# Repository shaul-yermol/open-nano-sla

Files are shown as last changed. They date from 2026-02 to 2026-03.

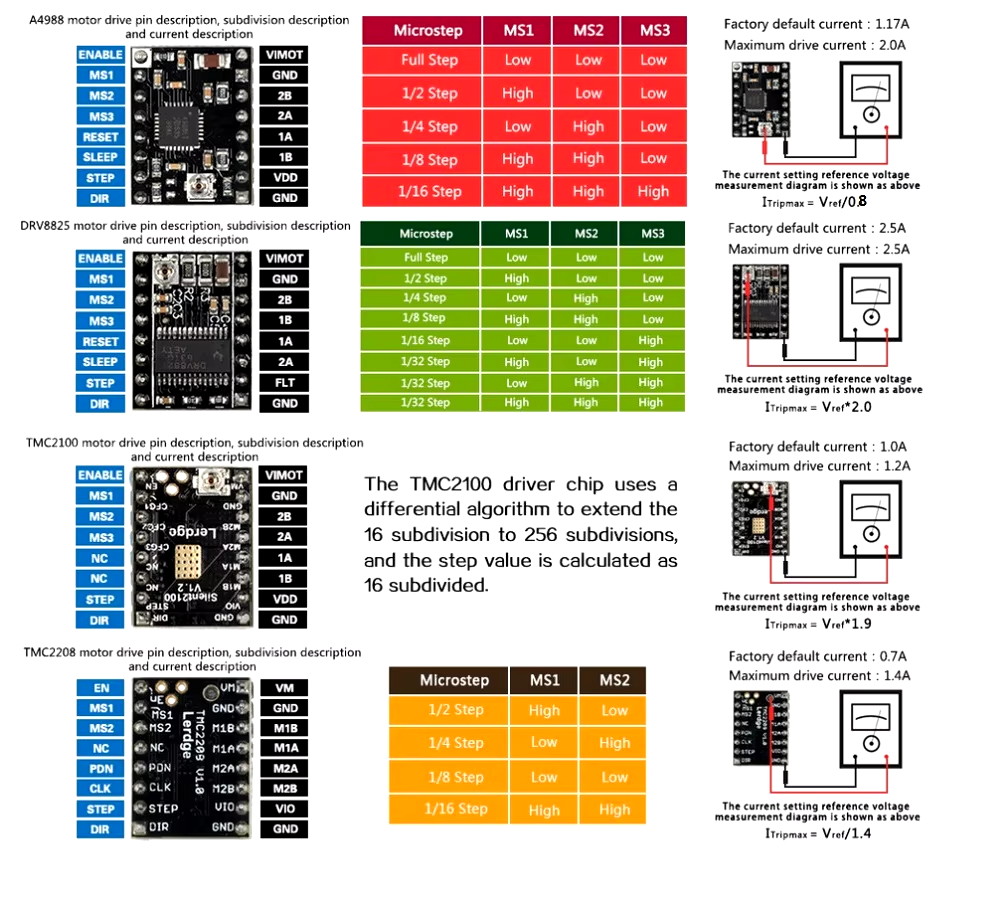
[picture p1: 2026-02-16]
cad/nano-dlp/microsteps.png

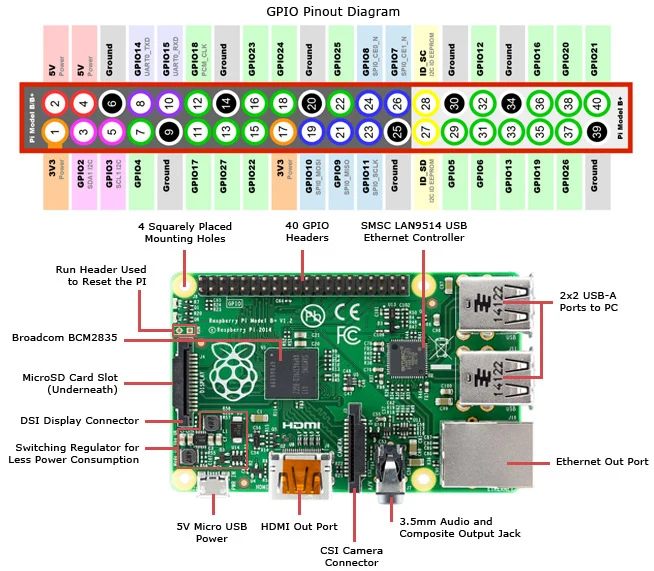
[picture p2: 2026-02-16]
cad/nano-dlp/Pi3_connectors.png

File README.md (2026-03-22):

# Set static IP for Raspberry Pi via cmdline.txt

Example of /boot/cmdline.txt:
ip=192.168.5.100::192.168.5.101:255.255.255.0:rpi:eth0:off

# Wnable WIFI via cmdline.txt

nmcli networking on
nmcli device wifi connect 3C:84:6A:58:4C:27 password "your-password"
sudo nmcli device wifi connect 00:B8:C2:B1:13:42 password
sudo route del 192.168.5.101

# Toggle UV light via GPIO
gpioset GPIO26=0

# Reading endstop state
## TOP:
gpiomon GPIO25
## BOTTOM:
gpiomon GPIO13

# Step motor driver:
DRV8825
1/32 microstepping
STEP = GPIO23
DIR = GPIO22
ENABLE=GPIO24 (active low)

```
# Enable driver
gpioset GPIO24=0
# Step forward 100 steps
for i in `seq 100`; do gpioset -t 1,1,0 GPIO23=1; done
# Step backward 100 steps
for i in `seq 100`; do gpioset -t 1,1 GPIO23=0; gpioset -t 1,1 GPIO23=1; done
# Disable driver
gpioset GPIO24=1
```

# Show images on HDMI display
sudo apt-get install fbi
sudo fbi -T 2 -d /dev/fb0 -noverbose [imagefile.jpg] 

# NEXTION
Connected to GPIO14 (TX) and GPIO15 (RX) - instead of serial console (UART)
1. Disable serial console in raspi-config
2. Enable serial port hardware in raspi-config
3. Add to /boot/config.txt:
   enable_uart=1
   dtoverlay=disable-bt
4. Disable bluetooth to free up UART:
   sudo systemctl disable hciuart
5. Reboot

# G-code Commands Supported by Motor Controller

The motor controller (`mc.py`) supports the following G-code commands:

## Movement Commands

### G0, G1 - Linear Move
**Syntax:** `G0 Z<position> F<speed>` or `G1 Z<position> F<speed>`

- **Z**: Z-axis position in millimeters (relative movement)
  - Positive values move UP
  - Negative values move DOWN  
- **F**: Feed rate (speed) in microseconds between steps (optional, default: 600)

**Examples:**
```gcode
G1 Z10        # Move up 10mm at default speed
G0 Z-5 F400   # Move down 5mm at 400µs speed
G1 Z2.5       # Move up 2.5mm
```

## Homing Commands

### G28 - Home to Bottom Endstop
**Syntax:** `G28` or `G28 Z`

Moves the Z-axis down until the bottom endstop is triggered, then performs precision homing sequence.

**Examples:**
```gcode
G28           # Home to bottom endstop
G28 Z         # Home Z-axis to bottom
```

### G27 - Park/Home to Top Endstop  
**Syntax:** `G27` or `G27 Z`

Moves the Z-axis up until the top endstop is triggered, then performs precision homing sequence.

**Examples:**
```gcode
G27           # Park at top endstop
G27 Z         # Home Z-axis to top
```

## Timing Commands

### G4 - Dwell/Pause
**Syntax:** `G4 P<time>`

- **P**: Pause time in milliseconds

**Examples:**
```gcode
G4 P1000      # Pause for 1 second (1000ms)
G4 P500       # Pause for 0.5 seconds
```

## Motor Control Commands

### M17 - Enable Motors
**Syntax:** `M17`

Enables the stepper motor (sets ENABLE pin low).

### M18, M84 - Disable Motors
**Syntax:** `M18` or `M84`

Disables the stepper motor (sets ENABLE pin high). Motor will lose holding torque.

## UV Light Control Commands

### M3, M4 - UV Light On
**Syntax:** `M3` or `M4`

Turns on the UV light (sets UV_LIGHT_PIN high).

### M5 - UV Light Off
**Syntax:** `M5`

Turns off the UV light (sets UV_LIGHT_PIN low).

## Status Commands

### M119 - Report Endstop Status
**Syntax:** `M119`

Reports the current state of both endstops:
- **TRIGGERED**: Endstop is activated
- **OPEN**: Endstop is not activated

**Example Output:**
```
Top endstop (GPIO25): OPEN
Bottom endstop (GPIO13): TRIGGERED
```

## Usage Examples

### Basic Print Sequence
```gcode
M17           # Enable motor
G28           # Home to bottom
G1 Z0.1 F400  # Move to first layer height
M3            # Turn on UV light
G4 P5000      # Expose for 5 seconds
M5            # Turn off UV light
G1 Z0.1       # Move up one layer
M18           # Disable motor
```

### Status Check Sequence
```gcode
M119          # Check endstop status
M17           # Enable motor
G1 Z1         # Small test move
M119          # Check status again
M18           # Disable motor
```

## Command Interface

Commands can be sent to the motor controller via:
- **Named pipe**: `/tmp/mcin` (default)
- **Status output**: `/tmp/mcout` (default)

### Sending Commands
```bash
# Single command
echo "G1 Z10" > /tmp/mcin

# Multiple commands
cat << EOF > /tmp/mcin
M17
G28
G1 Z5
M18
EOF
```

### Monitoring Status
```bash
# Monitor status output
cat /tmp/mcout

# Or tail for continuous monitoring
tail -f /tmp/mcout
```

## Motor Controller Configuration

### Command Line Options
```bash
python3 mc.py --help
```

**Available Options:**
- `--check`: Check endstop status and exit
- `--home`: Home motor to bottom endstop and exit
- `--unhome`: Home motor to top endstop and exit  
- `--pipe`: Start G-code pipe service (main mode)
- `--pipe-path PATH`: Set input pipe path (default: `/tmp/mcin`)
- `--status-pipe PATH`: Set status output pipe path (default: `/tmp/mcout`)
- `--log-level LEVEL`: Set logging level (DEBUG, INFO, WARNING, ERROR, CRITICAL)
- `--log-file FILE`: Log to file in addition to console
- `-t TIME`: Set step delay in microseconds (default: 600)

### Usage Examples
```bash
# Start with debug logging
python3 mc.py --pipe --log-level DEBUG

# Use custom pipe paths
python3 mc.py --pipe --pipe-path /tmp/my_gcode --status-pipe /tmp/my_status

# Log to file with INFO level
python3 mc.py --pipe --log-file /var/log/motor.log --log-level INFO

# Quick endstop check
python3 mc.py --check

# Home the motor
python3 mc.py --home
```

### Hardware Configuration

**GPIO Pin Mapping:**
- **STEP**: GPIO23 (Step signal)
- **DIR**: GPIO22 (Direction signal) 
- **ENABLE**: GPIO24 (Enable signal, active low)
- **TOP_ENDSTOP**: GPIO25 (Top limit switch)
- **BOTTOM_ENDSTOP**: GPIO13 (Bottom limit switch)
- **UV_LIGHT**: GPIO26 (UV light control)

**Physical Parameters:**
- **Revolution**: 2mm per revolution
- **Microstepping**: 1/1 (full step)
- **Steps per revolution**: 200 steps

### Status Output Format

The status pipe outputs the following message types:

**Command Execution:**
```
EXEC:<gcode_command>     # Command started
OK                       # Command completed successfully  
ERROR                    # Command failed
```

**Movement Status:**
```
MOVE_COMPLETE:<direction>:<distance>mm:<steps>steps
HOME_COMPLETE:<direction>
```

**Queue Status:**
```
QUEUED:<gcode_command>   # Command added to queue
```

### Error Handling

**Common Error Messages:**
- `Invalid G-code: <command>` - Unrecognized command format
- `Unsupported G-code command: <command>` - Command not implemented  
- `No Z parameter found in G-code command` - Missing required Z parameter
- `G4: Missing P parameter for dwell time` - Missing required P parameter
- `G28: Only Z-axis homing supported` - X/Y homing not supported

## pigpio pigs interface

### Write to pin:

> pigs w 26 1
> pigs w 26 0

### Create and transmit waveform:

> pigs wvnew
> pigs wvag 0x800000 0x0 600 0x0 0x800000 600
2
> pigs wvcre
0
> pigs wvtxr 0
5
> pigs wvhlt

### Endstop control:

> pigs m 25 r
> pigs m 13 r
> pigs fg 25 100
> pigs fg 13 100
> pigs procr 1
> pigs procr 1
> pigs proc wait 0x2002000 w 24 1
> pigs proc 2

### UI dependencies:

https://github.com/adafruit/Adafruit_CircuitPython_RGB_Display.git
https://github.com/ilbertt/XPT2046-Python/blob/main/xpt2046.py

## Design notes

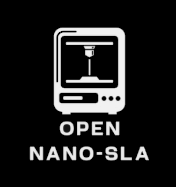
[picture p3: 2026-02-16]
open-nano-sla-bw.png

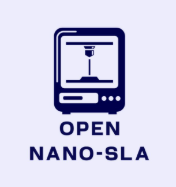
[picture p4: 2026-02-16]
open-nano-sla.png

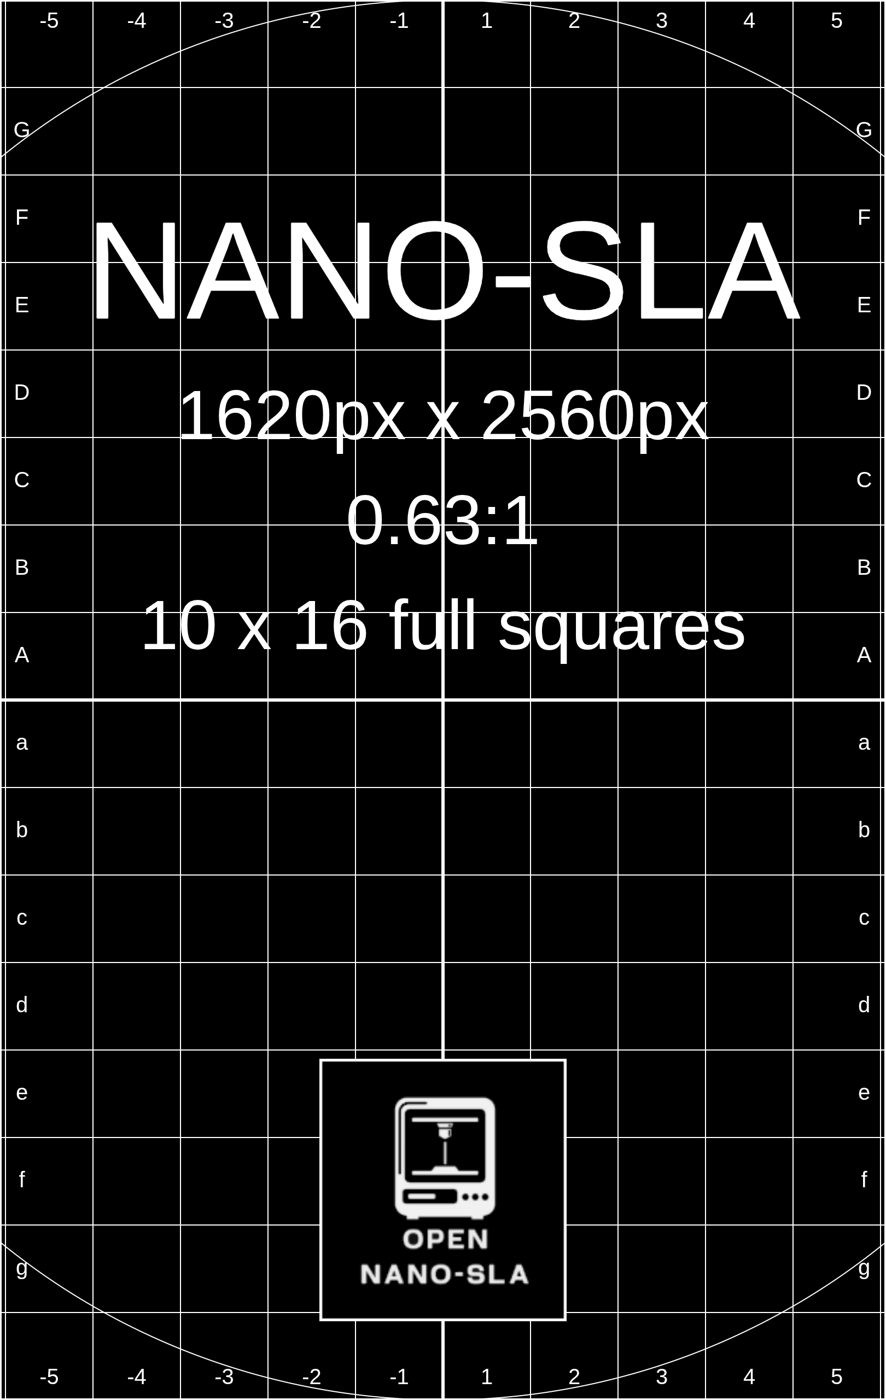
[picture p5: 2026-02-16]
NANO-SLA_1620x2560.png

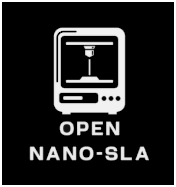
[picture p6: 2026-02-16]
open-nano-sla-bw-bb.png

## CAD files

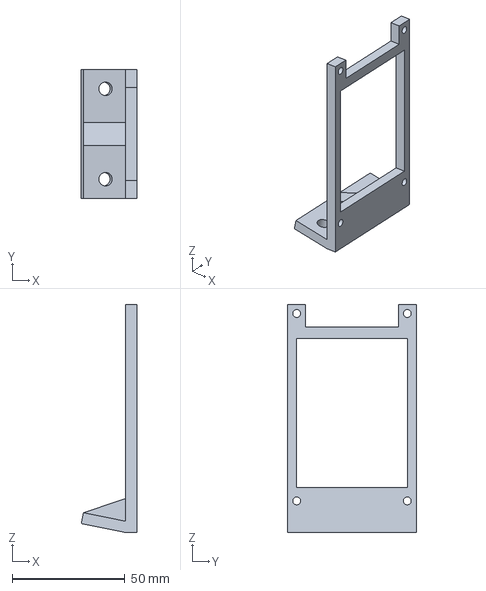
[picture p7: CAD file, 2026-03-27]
cad/LCD-cable-brackeer.FCStd
24.6 x 57.0 x 101.0 mm

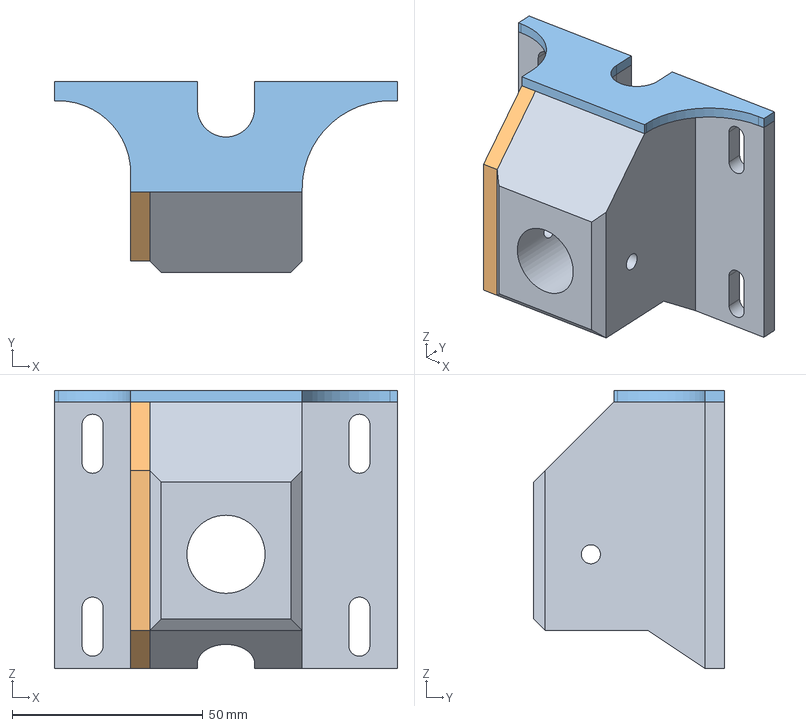
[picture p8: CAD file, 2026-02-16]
cad/sla Z Body.FCStd
90.0 x 50.0 x 73.0 mm
Z Body
Z Body Side str
Z Body Top str

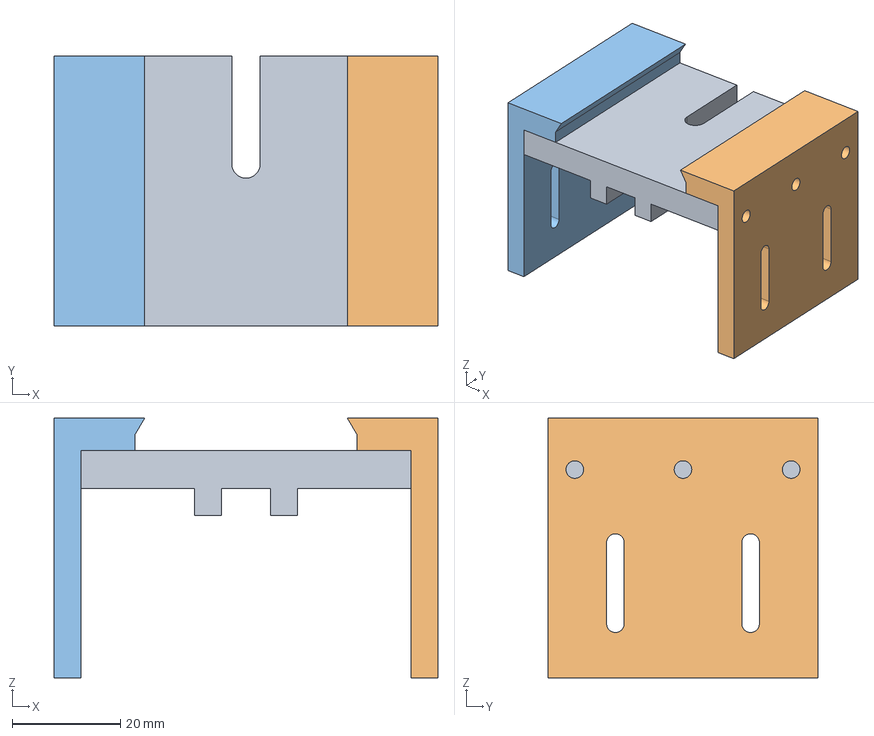
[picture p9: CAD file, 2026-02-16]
cad/sla_plate_holder.FCStd
71.0 x 50.0 x 48.0 mm
Slice.0
Slice.1
Slice.2

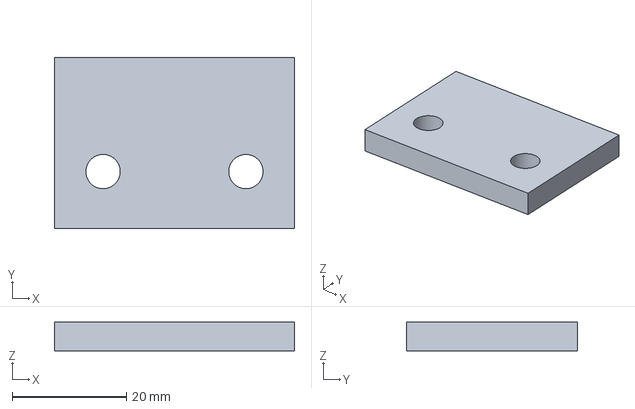
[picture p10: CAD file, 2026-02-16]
cad/sla_plate_holder_wall.FCStd
42.0 x 30.0 x 5.00 mm

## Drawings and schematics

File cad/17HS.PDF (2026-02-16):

# Hybrid Stepper Motor

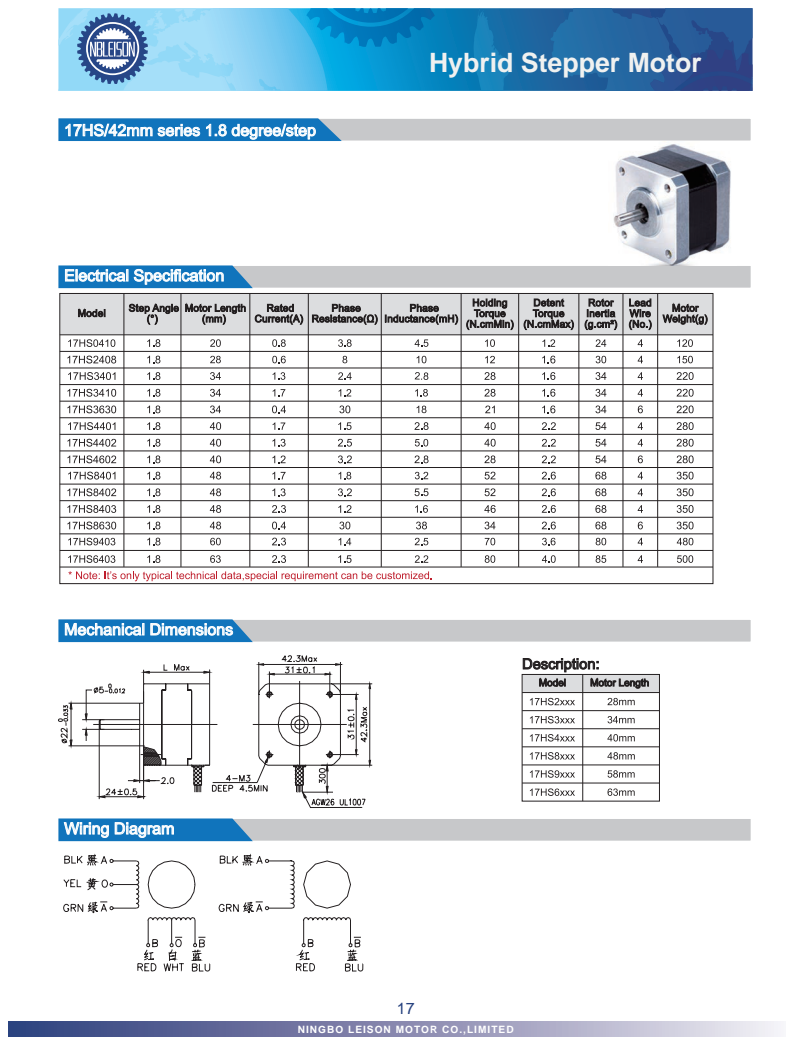
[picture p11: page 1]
Model; Motor Length; Description:; Mechanical Dimensions; Electrical Specification; Wiring Diagram

17HS/42mm series 1.8 degree/step

NINGBO LEISON MOTOR CO.,LIMITED

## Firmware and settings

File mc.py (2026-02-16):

#!/usr/bin/env python3

# This is a motor controller module for a robot using GPIO pins to control motors.
import subprocess
import time
import argparse
import re
import os
import sys
import queue
import threading
from dataclasses import dataclass
from typing import Optional
from threading import Lock
import logging
import logging.handlers
import errno
import posix

# Configure logging with syslog
def setup_logging(log_level='INFO', use_syslog=True):
    """Setup logging configuration with syslog support"""
    numeric_level = getattr(logging, log_level.upper(), logging.INFO)
    
    # Get root logger and set level
    root_logger = logging.getLogger()
    root_logger.setLevel(numeric_level)
    
    # Remove existing handlers
    for handler in root_logger.handlers[:]:
        root_logger.removeHandler(handler)
    
    if use_syslog:
        # Create syslog handler
        try:
            syslog_handler = logging.handlers.SysLogHandler(address='/dev/log')
            # Set format for syslog (no timestamp needed, syslog adds it)
            syslog_formatter = logging.Formatter(
                fmt='mc.py[%(process)d]: %(name)s - %(levelname)s - %(message)s'
            )
            syslog_handler.setFormatter(syslog_formatter)
            root_logger.addHandler(syslog_handler)
        except Exception as e:
            # Fallback to console if syslog fails
            print(f"Warning: Could not connect to syslog, using console: {e}")
            use_syslog = False
    
    if not use_syslog:
        # Create console handler as fallback
        console_handler = logging.StreamHandler(sys.stdout)
        console_formatter = logging.Formatter(
            fmt='%(asctime)s - %(name)s - %(levelname)8s - %(message)s',
            datefmt='%Y-%m-%d %H:%M:%S'
        )
        console_handler.setFormatter(console_formatter)
        console_handler.setFormatter(console_formatter)
        root_logger.addHandler(console_handler)
    
    return logging.getLogger(__name__)

# Initialize logger (will be reconfigured in main if needed)
logger = setup_logging()

# Helper functions for pigpio pigs interface
def pigs_cmd(*args):
    """Execute a pigs command and return the output"""
    try:
        result = subprocess.run(['pigs'] + list(map(str, args)), 
                              capture_output=True, text=True, check=True)
        outVal = result.stdout.strip()
        logger.debug(f"pigs command output: {' '.join(map(str, args))} -> {outVal}")
        return outVal
    except subprocess.CalledProcessError as e:
        logger.error(f"pigs command failed: {' '.join(map(str, args))}, error: {e.stderr}")
        return None
    except Exception as e:
        logger.error(f"pigs command exception: {e}")
        return None

def gpio_write(pin, value):
    """Write to a GPIO pin using pigs (w command)"""
    return pigs_cmd('w', pin, 1 if value else 0)

def gpio_read(pin):
    """Read from a GPIO pin using pigs (r command)"""
    result = pigs_cmd('r', pin)
    return int(result) if result is not None else None

def gpio_mode(pin, mode):
    """Set GPIO pin mode using pigs (m command)
    mode: 'r' for read/input, 'w' for write/output
    """
    return pigs_cmd('m', pin, mode)

# Define GPIO pins for motor control (BCM numbering)
MOTOR_DIR_PIN = 22
MOTOR_STP_PIN = 23
MOTOR_EN_PIN = 24

# Define endstop pins (BCM numbering)
TOP_ENDSTOP_PIN = 25
BOTTOM_ENDSTOP_PIN = 13

#Define GPIO pins for UV light control (BCM numbering)
UV_LIGHT_PIN = 26

# Define directions
directions = ["u", "d"]

#define physical parameters
revolution_mm = 2.0                         # 2mm per revolution
microstepping = 32.0                         # 1/32 microstepping
full_steps_per_rev = 200.0 * microstepping  # Full steps per revolution for the stepper motor
default_speed = 2000                        # Default speed in microseconds between steps (adjust as needed)

# Initialize GPIO pins using pigs
def init_gpio():
    """Initialize GPIO pins for motor control, endstops, and UV light"""
    logger.info("Initializing GPIO pins with pigpio...")
    
    # Set motor control pins as outputs
    gpio_mode(MOTOR_DIR_PIN, 'w')
    gpio_mode(MOTOR_STP_PIN, 'w')
    gpio_mode(MOTOR_EN_PIN, 'w')
    
    # Set endstop pins as inputs with pull-up
    gpio_mode(TOP_ENDSTOP_PIN, 'r')
    gpio_mode(BOTTOM_ENDSTOP_PIN, 'r')
    pigs_cmd('pud', TOP_ENDSTOP_PIN, 'd')     # Set pull-up
    pigs_cmd('pud', BOTTOM_ENDSTOP_PIN, 'd')  # Set pull-up
    
    # Set UV light pin as output
    gpio_mode(UV_LIGHT_PIN, 'w')
    
    # Initialize pin states
    gpio_write(MOTOR_DIR_PIN, 0)  # Direction low
    gpio_write(MOTOR_STP_PIN, 0)  # Step low
    gpio_write(MOTOR_EN_PIN, 1)   # Motor disabled (active low)
    gpio_write(UV_LIGHT_PIN, 0)   # UV light off
    
    logger.info("GPIO initialization complete")

# Initialize GPIO on module load
init_gpio()

# Data class for G-code commands
@dataclass
class GCodeCommand:
    line: str
    line_number: int
    timestamp: float

# Global variables
status_pipe = None
g_gcode_queue = queue.Queue()
g_stop_threads = threading.Event()
g_pause_execution = threading.Event()
g_immediate_stop = threading.Event()

def init_status_pipe(pipe_path):
    """Initialize the status output pipe"""
    global status_pipe
    logger.info(f"Initializing status output pipe: {pipe_path}")
    if pipe_path:
        try:
            # Create the named pipe if it doesn't exist
            if not os.path.exists(pipe_path):
                os.mkfifo(pipe_path)
                os.chmod(pipe_path, 0o666)
                logger.info(f"Created status output pipe: {pipe_path}")
            status_pipe = pipe_path
            return True
        except Exception as e:
            logger.warning(f"Failed to initialize status pipe {pipe_path}: {e}")
            status_pipe = None
            return False
    return False

def write_status(message):
    """Write status message to output pipe if available"""
    global status_pipe
    if status_pipe:
        try:
            pipe = posix.open(status_pipe, posix.O_RDWR)
            # write to pipe
            logger.debug(f"Writing to status pipe: {message}")
            os.write(pipe, f"{message}\n".encode())
            os.close(pipe)
        except Exception as e:
            logger.warning(f"Failed to write to status pipe: {e}")
            # Try to reinitialize the pipe
            status_pipe = None

def parse_gcode(gcode_line):
    """Parse a G-code line and extract command and parameters"""
    # Remove whitespace and convert to uppercase
    gcode_line = gcode_line.strip().upper()
    
    # Extract command (G0, G1, etc.)
    command_match = re.match(r'^([GM]\d+)', gcode_line)
    if not command_match:
        return None, {}
    
    command = command_match.group(1)
    
    # Extract parameters (X, Y, Z, F, etc.)
    params_line = gcode_line[len(command):].strip()
    params = {}
    param_pattern = r'([A-Z])(-?\d*\.?\d+)'
    matches = re.findall(param_pattern, params_line)

    for param, value in matches:
        try:
            # Try to convert to float, fallback to int if no decimal
            if '.' in value:
                params[param] = float(value)
            else:
                params[param] = int(value)
        except ValueError:
            params[param] = value
    
    return command, params

def execute_gcode(gcode_line, default_speed=default_speed):
    """Execute a G-code command"""
    command, params = parse_gcode(gcode_line)
    
    if not command:
        logger.error(f"Invalid G-code: {gcode_line}")
        write_status("ERROR")
        return False
    
    logger.info(f"Executing G-code: {gcode_line}")
    logger.debug(f"Command: {command}, Parameters: {params}")
    write_status(f"EXEC:{gcode_line}")

    success = False

    if 'F' in params:
        speed = params['F']
    else:
        speed = default_speed

    # Extract Z parameter for vertical movement
    if 'Z' in params:
        z_pos = params['Z']
    else:
        z_pos = None

    if command in ['G0', 'G1']:  # Linear move (rapid or controlled)
        if z_pos is not None:
            
            # Convert Z position to steps (assuming current position is 0)
            # For now, we'll treat Z as relative movement in mm
            z_mm = float(z_pos)
            z_steps = round(abs(z_mm) * (full_steps_per_rev / revolution_mm))
            logger.debug(f"Z movement: {z_mm}mm -> {z_steps} steps at full_steps_per_rev {full_steps_per_rev}, revolution_mm {revolution_mm}")
            # Determine direction
            direction = "u" if z_mm > 0 else "d"

            logger.info(f"Moving Z-axis: {z_mm}mm ({z_steps} steps) in direction '{direction}' at speed {speed}us")
            
            # Execute movement with endstop protection
            use_endstops=True if command == 'G0' else False  # Use endstops for rapid moves (G0), not for controlled moves (G1)

            steps_moved = move_motor(direction, z_steps, int(speed), use_endstops=use_endstops, disable_at_end=False)
            write_status(f"MOVE_COMPLETE:{direction}:{z_mm}mm:{steps_moved}steps")
            
            success = True
        else:
            logger.warning("No Z parameter found in G-code command")
            success = False
    
    elif command == 'G28' or command == 'G27':  # Home command or Park toolhead
        axis = params.get('Z', None)
        all_axis = params.get('X', None) is None and params.get('Y', None) is None

        if axis is not None or all_axis:  # G28 Z or G28 (home all)
            logger.info("Homing Z-axis...")
            if (command == 'G27'):
                direction = 'u'
            if (command == 'G28'):
                direction = 'd'
            logger.info(f"Homing direction: {direction}, speed: {speed}")
            home_motor(speed, direction)
            write_status(f"HOME_COMPLETE:{direction}")
            success = True
        else:
            logger.warning("G28: Only Z-axis homing supported")
            success = False
    
    elif command == 'M17':  # Enable motors
        logger.info("Enabling motor...")
        gpio_write(MOTOR_EN_PIN, 0)  # Active low
        write_status("MOTOR_ENABLED")
        success = True
    
    elif command == 'M18' or command == 'M84':  # Disable motors
        logger.info("Disabling motor...")
        gpio_write(MOTOR_EN_PIN, 1)  # Active low
        write_status("MOTOR_DISABLED")
        success = True

    elif command == 'G4':  # Dwell
        if 'P' in params:
            dwell_time = params['P'] / 1000.0  # Convert milliseconds to seconds
            logger.info(f"Dwelling for {dwell_time} seconds...")
            for i in range(int(dwell_time * 10)):
                if g_immediate_stop.is_set():
                    logger.warning("Immediate stop requested during dwell")
                    break
                time.sleep(0.1)
            success = True
        else:
            logger.error("G4: Missing P parameter for dwell time")
            success = False
    
    elif command == 'M3' or command == 'M4':  # UV light on
        gpio_write(UV_LIGHT_PIN, 1)
        logger.info("UV light turned ON")
        write_status("UV_ON")
        success = True

    elif command == 'M5':  # UV light off
        gpio_write(UV_LIGHT_PIN, 0)
        logger.info("UV light turned OFF")
        write_status("UV_OFF")
        success = True

    elif command == 'M119':  # Report endstop status
        top_state = "TRIGGERED" if top_triggered() else "OPEN"
        bottom_state = "TRIGGERED" if bottom_triggered() else "OPEN"
        logger.info(f"Top endstop (GPIO{TOP_ENDSTOP_PIN}): {top_state}")
        logger.info(f"Bottom endstop (GPIO{BOTTOM_ENDSTOP_PIN}): {bottom_state}")
        write_status(f"ENDSTOPS:TOP={top_state},BOTTOM={bottom_state}")
        success = True

    else:
        logger.error(f"Unsupported G-code command: {command}")
        write_status("ERROR: UNSUPPORTED_COMMAND")
        success = False
    
    # Report final execution status
    if success:
        write_status("OK")
    else:
        write_status("ERROR")
    
    return success


def top_triggered() -> bool:
    """Check if the top endstop is triggered"""
    # Active low: triggered when the pin reads low (0)
    value = gpio_read(TOP_ENDSTOP_PIN)
    return value == 0 if value is not None else False

def bottom_triggered() -> bool:
    """Check if the bottom endstop is triggered"""
    # Active low: triggered when the pin reads low (0)
    value = gpio_read(BOTTOM_ENDSTOP_PIN)
    return value == 0 if value is not None else False

def check_endstops():
    """Check and print current endstop states"""
    top_state = "TRIGGERED" if top_triggered() else "OPEN"
    bottom_state = "TRIGGERED" if bottom_triggered() else "OPEN"
    logger.info(f"Top endstop (GPIO{TOP_ENDSTOP_PIN}): {top_state}")
    logger.info(f"Bottom endstop (GPIO{BOTTOM_ENDSTOP_PIN}): {bottom_state}")
    return top_triggered(), bottom_triggered()

def home_motor(speed=default_speed, direction="d"):

    disable_at_end = True

    """Home the motor by moving to bottom endstop"""
    logger.info(f"Homing motor to {direction} endstop...")
    steps_moved = move_motor(direction, 999999, speed, disable_at_end)  # Move until endstop
    logger.info(f"Motor homed to {direction} endstop after {steps_moved} steps.")

    slow_speed = speed * 1

    # Move up a bit in opposite direction to avoid constant endstop triggering
    if direction == "d":
        steps_moved = move_motor("u", int(full_steps_per_rev), slow_speed, disable_at_end)
    else:
        steps_moved = move_motor("d", int(full_steps_per_rev), slow_speed, disable_at_end)

    time.sleep(0.25)
    # Move slowly again to re-engage endstop
    steps_moved = move_motor(direction, int(1.1 * full_steps_per_rev), slow_speed, disable_at_end)

    time.sleep(0.25)

    if direction == "d":
        steps_moved = move_motor("u", int(full_steps_per_rev), slow_speed, disable_at_end)
    else:
        steps_moved = move_motor("d", int(full_steps_per_rev), slow_speed, disable_at_end)

    time.sleep(0.25)
    # Move slowly again to re-engage endstop
    steps_moved = move_motor(direction, int(1.1 * full_steps_per_rev), slow_speed, disable_at_end)

    time.sleep(0.25)

    logger.info(f"Homing complete. Motor position is now at {direction} endstop.")
    return steps_moved

def move_motor(direction, steps, speed, use_endstops, disable_at_end=False):

    _top_triggered = top_triggered()
    _bottom_triggered = bottom_triggered()

    steps_moved = 0

    # Set motor direction
    if direction == "u":
        gpio_write(MOTOR_DIR_PIN, 0)
        endstop = TOP_ENDSTOP_PIN
    else:
        gpio_write(MOTOR_DIR_PIN, 1)
        endstop = BOTTOM_ENDSTOP_PIN

    # Enable motor (active low)
    gpio_write(MOTOR_EN_PIN, 0)

    end_stop_command=f"r {endstop} jnz 321 " if use_endstops else ""
    proc_command = f"proc tag 123 w {MOTOR_STP_PIN} 1 mics {round(speed/microstepping)} w {MOTOR_STP_PIN} 0 mics {round(speed/microstepping)} {end_stop_command} dcr p0 jnz 123 tag 321"
    proc_id = pigs_cmd(proc_command)
    pigs_cmd('procr', proc_id, steps)  # Run procedure

    while True:
        time.sleep(0.1)  # Sleep briefly to avoid busy waiting
        procp = pigs_cmd('procp', proc_id).split()  # Check procedure status
        if g_immediate_stop.is_set():
            logger.warning("Immediate stop requested")
            pigs_cmd('procs', proc_id)  # Stop procedure
            break        
        if len(procp) < 11:
            logger.error("Failed to get procedure status")
            break
        status = procp[0]
        steps_remaining = int(procp[1])
        logger.debug(f"Procedure status: {status}, steps remaining: {steps_remaining}")
        if status != '2':
            steps_moved = steps - steps_remaining
            logger.debug(f"Steps moved so far: {steps_moved}")
            break

    pigs_cmd('procd', proc_id)  # Delete procedure

    # Disable motor (active low)
    if disable_at_end:
        gpio_write(MOTOR_EN_PIN, 1)
    
    if steps_moved == steps:
        logger.info(f"Moved {direction} for {steps} steps at speed {speed}us")
    else:
        logger.info(f"Movement stopped early at {steps_moved}/{steps} steps due to endstop")
    
    return steps_moved

def create_named_pipe(pipe_path="/tmp/mcin"):
    """Create a named pipe (FIFO) for G-code input"""
    try:
        # Remove existing pipe if it exists
        if os.path.exists(pipe_path):
            os.unlink(pipe_path)
        
        # Create named pipe
        os.mkfifo(pipe_path)
        logger.info(f"Created named pipe: {pipe_path}")
        
        # Set permissions so other processes can write to it
        os.chmod(pipe_path, 0o666)
        
        return True
    except Exception as e:
        logger.error(f"Error creating named pipe {pipe_path}: {e}")
        return False

def read_gcode_from_pipe(pipe_path="/tmp/mcin"):
    """Read G-code commands from named pipe and add them to the queue"""
    logger.info(f"Reading G-code from named pipe: {pipe_path}")
    
    line_number = 1
    
    try:
        # Open the named pipe for reading
        while not g_stop_threads.is_set():
            with open(pipe_path, 'r') as pipe:
                try:
                    logger.debug("Waiting for G-code command...")
                    # Read line from pipe (blocking)
                    line = pipe.readline()
                    
                    # If readline returns empty string, pipe was closed by writer
                    if not line:
                        logger.debug("Pipe closed by writer, reopening...")
                        continue
                    
                    line = line.strip()
                    
                    # Skip empty lines and comments
                    if not line or line.startswith(';') or line.startswith('#'):
                        continue
                    
                    logger.info(f"Received G-code[{line_number}]: {line}")
                    
                    # Create command object and add to queue
                    command = GCodeCommand(
                        line=line,
                        line_number=line_number,
                        timestamp=time.time()
                    )
                    g_gcode_queue.put(command)
                    # write_status(f"QUEUED:{line}")
                    
                    line_number += 1
                    
                except KeyboardInterrupt:
                    logger.info("Stopping G-code pipe reader...")
                    break
                    
    except Exception as e:
        logger.error(f"Error reading G-code from pipe {pipe_path}: {e}")
    
    logger.info("G-code pipe reader stopped.")

def process_gcode_queue(default_speed=default_speed):
    """Process G-code commands from the queue"""
    logger.info("Starting G-code queue processor...")
    
    while not g_stop_threads.is_set():
        try:
            # Get command from queue with timeout
            try:
                command = g_gcode_queue.get(timeout=1.0)
            except queue.Empty:
                continue
            
            logger.info(f"Processing G-code[{command.line_number}]: {command.line} (queue size: {g_gcode_queue.qsize()})")
            
            # Execute the G-code command
            success = execute_gcode(command.line, default_speed)
            
            if success:
                logger.info(f"✓ Line {command.line_number}: Command executed successfully")
            else:
                logger.error(f"✗ Line {command.line_number}: Command failed")

            logger.debug(f"Queue size after processing: {g_gcode_queue.qsize()}")

        except KeyboardInterrupt:
            logger.info("Stopping G-code queue processor...")
            break
        except Exception as e:
            logger.error(f"Error processing G-code command: {e}")
            # Still mark task as done to prevent queue from hanging
            try:
                g_gcode_queue.task_done()
            except ValueError:
                pass  # task_done() called too many times

    logger.info("G-code queue processor stopped.")

def get_queue_status():
    """Get current queue status"""
    return {
        'queue_size': g_gcode_queue.qsize(),
        'threads_stopped': g_stop_threads.is_set()
    }

def execute_gcode_from_pipe_with_queue(pipe_path="/tmp/mcin", default_speed=default_speed):
    """Start both pipe reader and queue processor threads"""
    logger.info("Starting G-code service with queue...")
    logger.info("Send G-code commands to the pipe using: echo 'G1 Z10' > /tmp/mcin")
    logger.info("Press Ctrl+C to stop the service")
    
    # Reset stop event
    g_stop_threads.clear()
    
    # Start reader thread
    reader_thread = threading.Thread(
        target=read_gcode_from_pipe,
        args=(pipe_path,),
        daemon=True
    )
    
    # Start processor thread  
    processor_thread = threading.Thread(
        target=process_gcode_queue,
        args=(default_speed,),
        daemon=True
    )
    
    try:
        reader_thread.start()
        processor_thread.start()
        
        logger.info("G-code service threads started")
        
        # Wait for threads to finish or keyboard interrupt
        while reader_thread.is_alive() or processor_thread.is_alive():
            time.sleep(0.1)
            
    except KeyboardInterrupt:
        logger.info("Shutting down G-code service...")
        g_stop_threads.set()
        
        # Wait for threads to finish
        reader_thread.join(timeout=2.0)
        processor_thread.join(timeout=2.0)
        
        logger.info("G-code service stopped.")
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

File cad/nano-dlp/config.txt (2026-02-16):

# For more options and information see
# http://rpf.io/configtxt
# Some settings may impact device functionality. See link above for details

# uncomment if you get no picture on HDMI for a default "safe" mode
# hdmi_safe=1

# uncomment this if your display has a black border of unused pixels visible
# and your display can output without overscan
#disable_overscan=1

# uncomment the following to adjust overscan. Use positive numbers if console
# goes off screen, and negative if there is too much border
#overscan_left=16
#overscan_right=16
#overscan_top=16
#overscan_bottom=16

# uncomment to force a console size. By default it will be display's size minus
# overscan.
#framebuffer_width=1280
#framebuffer_height=720

# uncomment if hdmi display is not detected and composite is being output
#hdmi_force_hotplug=1

# uncomment to force a specific HDMI mode (this will force VGA)
#hdmi_group=1
#hdmi_mode=1

# uncomment to force a HDMI mode rather than DVI. This can make audio work in
# DMT (computer monitor) modes
#hdmi_drive=2

# uncomment to increase signal to HDMI, if you have interference, blanking, or
# no display
#config_hdmi_boost=4

# uncomment for composite PAL
#sdtv_mode=2

#uncomment to overclock the arm. 700 MHz is the default.
#arm_freq=800

# Uncomment some or all of these to enable the optional hardware interfaces
#dtparam=i2c_arm=on
#dtparam=i2s=on
#dtparam=spi=on

# Uncomment this to enable the lirc-rpi module
#dtoverlay=lirc-rpi

# Additional overlays and parameters are documented /boot/overlays/README

# Enable audio (loads snd_bcm2835)
dtparam=audio=on

disable_splash=1
boot_delay=0
dtoverlay=pi3-disable-bt

[pi4]
# Enable DRM VC4 V3D driver on top of the dispmanx display stack
dtoverlay=vc4-fkms-v3d
max_framebuffers=2

[all]
#dtoverlay=vc4-fkms-v3d
disable_camera_led=1

hdmi_pixel_encoding=2
start_x=0
gpu_mem=128
enable_uart=1


hdmi_drive=2

# tells the Pi to output a signal even if an HDMI display is not detected.
hdmi_force_hotplug:1=1

# Limit freq to 300Mhz
hdmi_pixel_freq_limit:1=300000000

# Set HDMI to DMT mode 87 (custom mode)
hdmi_group:1=2
hdmi_mode:1=87

# To disable the black border around the screen, use:
disable_overscan:1=1
config_hdmi_boost:1=4

# hdmi_timings:1=540 0 35 14 35 2400 0 62 6 28 0 0 0 50 0 170000000 0 
framebuffer_width:1=540
framebuffer_height:1=2560
# display_rotate=3
max_framebuffer_width:1=2560
max_framebuffer_height:1=2560

framebuffer_ignore_alpha=1
framebuffer_depth=24

hdmi_cvt=540 2560 50

# TODO: Check this
# hvs_priority=0x32ff


# force_trubo=1
# gpu_freq=300
# core_freq=400

display_rotate=0x10000
dtparam=audio=off

# guessing the format to be 540x2560p @50 Hz
# 540x2560p hfp:76 hs:10 hbp:56 vfp:50 vs:2 vbp:20 pixel clock:89 MHz
# hdmi_timings:1=540 0 76 10 56 2560 0 50 2 20 0 0 0 50 0 89000000 0 

# hdmi_timings=[h_active_pixels] [h_sync_polarity] [h_front_porch] [h_sync_pulse] [h_back_porch] [v_active_lines] [v_sync_polarity] [v_front_porch] [v_sync_pulse] [v_back_porch] [v_sync_offset_a] [v_sync_offset_b] [pixel_rep] [frame_rate] [interlaced] [pixel_freq] [aspect_ratio]
# hdmi_timings:1=540 0 76 10 56 2560 0 50 2 20 0 0 0 50 0 89000000 0

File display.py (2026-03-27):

import json
import os
import sys
import time
import select
import busio
import digitalio
from board import SCK, MOSI, MISO, D8, D7, D1, D2
import subprocess
import zipfile

from gpiozero import Button as GpioButton

from adafruit_rgb_display import color565
import adafruit_rgb_display.ili9341 as ili9341

from PIL import Image, ImageDraw, ImageFont

from xpt2046 import Touch
from ui import screens, Screen, SCREEN_W, SCREEN_H, print_screen, confirm_screen, printing_screen

import logging
import logging.handlers

# Configure logging with syslog
def setup_logging(log_level='DEBUG', use_syslog=True):
    """Setup logging configuration with syslog support"""
    numeric_level = getattr(logging, log_level.upper(), logging.INFO)
    
    # Get root logger and set level
    root_logger = logging.getLogger()
    root_logger.setLevel(numeric_level)
    
    # Remove existing handlers
    for handler in root_logger.handlers[:]:
        root_logger.removeHandler(handler)
    
    if use_syslog:
        # Create syslog handler
        try:
            syslog_handler = logging.handlers.SysLogHandler(address='/dev/log')
            # Set format for syslog (no timestamp needed, syslog adds it)
            syslog_formatter = logging.Formatter(
                fmt='display.py[%(process)d]: %(name)s - %(levelname)s - %(message)s'
            )
            syslog_handler.setFormatter(syslog_formatter)
            root_logger.addHandler(syslog_handler)
        except Exception as e:
            # Fallback to console if syslog fails
            logger.warning(f"Could not connect to syslog, using console: {e}")
            use_syslog = False
    
    if not use_syslog:
        # Create console handler as fallback
        console_handler = logging.StreamHandler(sys.stdout)
        console_formatter = logging.Formatter(
            fmt='%(asctime)s - %(name)s - %(levelname)8s - %(message)s',
            datefmt='%Y-%m-%d %H:%M:%S'
        )
        console_handler.setFormatter(console_formatter)
        console_handler.setFormatter(console_formatter)
        root_logger.addHandler(console_handler)
    
    return logging.getLogger(__name__)

# Initialize logger (will be reconfigured in main if needed)
logger = setup_logging()


# ── Load touch calibration (if available) ────────────────────────────────
_CAL_FILE = os.path.join(os.path.dirname(os.path.abspath(__file__)),
                         "touch_cal.json")
_touch_cal = {}
if os.path.isfile(_CAL_FILE):
    with open(_CAL_FILE) as f:
        _touch_cal = json.load(f)
    logger.info(f"Loaded touch calibration: {_touch_cal}")
else:
    logger.warning("No touch_cal.json found – using defaults.  Run touch-test.py to calibrate.")


# ── SPI bus ──────────────────────────────────────────────────────────────
spi = busio.SPI(clock=SCK, MOSI=MOSI, MISO=MISO)

# ── Display (ILI9341) ───────────────────────────────────────────────────
DISPLAY_CS = D8
DC_PIN = D1

disp = ili9341.ILI9341(spi, cs=digitalio.DigitalInOut(DISPLAY_CS),
                          dc=digitalio.DigitalInOut(DC_PIN))

width = disp.width
height = disp.height
image = Image.new("RGB", (SCREEN_W, SCREEN_H))
draw = ImageDraw.Draw(image)

rotation = 180

# ── Touch controller (XPT2046, shares SPI, separate CS on D7) ───────────
touch_cs = digitalio.DigitalInOut(D7)
touch_irq = GpioButton(3, bounce_time = 0.15)           # GPIO3 interrupt pin


# ── Screen navigation ────────────────────────────────────────────────────
current_screen: Screen = screens["main"]


def show_screen(name: str):
    """Switch to a different screen and refresh the display."""
    global current_screen
    if name == "print":
        print_screen.refresh_files()
    current_screen = screens[name]
    current_screen.draw(draw, image)
    disp.image(image, rotation)

def on_move(distance_mm: float):
    """Return a function that moves the Z axis by the given distance."""
    logging.info(f"Moving Z by {distance_mm} mm")

flood_state = False
test_state = False

def on_led(led_name: str):
    """Toggle the given LED."""
    global flood_state, test_state
    if led_name == "FLOOD":
        flood_state = not flood_state
        logging.info(f"Toggling LED: {led_name} to {'ON' if flood_state else 'OFF'}")
    elif led_name == "TEST":
        test_state = not test_state
        logging.info(f"Toggling LED: {led_name} to {'ON' if test_state else 'OFF'}")

def on_print(file_path: str) -> bool:
    """Start printing the given file."""
    logging.info(f"Starting print job: {file_path}")
   
    # Verify the file exists before attempting to print
    if not os.path.isfile(file_path):
        logging.error(f"File not found: {file_path}")
        return False
    
    # verify the file has a .sl1 extension
    if not file_path.lower().endswith('.sl1'):
        logging.error(f"Invalid file type (expected .sl1): {file_path}")
        return False

    try:

        # Get the filename without path and extension for display/logging purposes
        filename = os.path.basename(file_path)
        logging.info(f"Preparing to print file: {filename}")

        # Unzip the file if it's a .sl1 archive:        
        with zipfile.ZipFile(file_path, 'r') as zip_ref:
            # Extract to /tmp/ + filename without extension
            extract_path = os.path.join("/tmp", os.path.splitext(filename)[0])
            zip_ref.extractall(extract_path)
            logging.info(f"Extracted {filename} to {extract_path}")
        
        # run print.py in a subprocess and continue immediately (print.py will communicate back via the UI pipe)
        subprocess.Popen(["python3", "print.py", "--log-level=DEBUG", "--dry-run", extract_path])
        logging.info(f"Started print.py subprocess for: {extract_path}")

        # subprocess.run(["path/to/printer_command", file_path])
        # For this example, we'll just log the action.
        logging.info(f"Print command executed for: {file_path}")
    
    except zipfile.BadZipFile:
        logging.error(f"File is not a valid zip archive: {file_path}")
        return False
    except Exception as e:
        logging.error(f"Error starting print job for {file_path}: {e}")
        return False

    return True

# ── Confirmation helpers ─────────────────────────────────────────────────

def _show_confirm(title: str, message: str, action_name: str,
                  action_data=None):
    """Configure and show the generic confirmation screen."""
    confirm_screen.configure(title, message, action_name, action_data)
    show_screen("confirm")
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

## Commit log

2026-02-04 Add motor controller and image processing scripts
    - Implemented mc.py for motor control with GPIO, including G-code parsing and execution.
    - Added print.py for managing the printing sequence, including image preprocessing and UV exposure control.
    - Introduced convert_image.py for converting grayscale images to RGB format.
    - Created config.txt for hardware configuration settings.
    - Added Test_converted.png as a sample output image.
    - Enhanced logging capabilities across all scripts for better debugging and monitoring.
    [config.txt]
2026-02-04 Update .gitignore to include test prints, SLA, and remote directories
2026-02-08 Refactor motor control logic and improve logging for pigs commands
2026-02-16 Update for MKS Motor + 32microstepping
2026-02-16 nano-dlp - for reference
    [config.txt]
2026-02-16 OLD 17HS motor doc
2026-02-16 Update .gitignore to include cad/stl, .gcode, and .FCBak files
2026-02-16 Reflector cad
2026-03-02 Add emergency stop pin definition for motor control
2026-03-22 Refactor print.py for UI integration and G-code handling
    - Updated pipe paths for mc.py and added UI communication pipes.
    - Introduced send_ui function to handle UI commands with a short timeout.
    - Enhanced logging levels and improved error handling in send_gcode and send_ui.
    - Modified main printing loop to update UI with layer progress and completion status.
    - Adjusted sleep durations for image display timing.
    Add supervisor configuration files for process management
    - Created mc.conf for managing mc.py process with supervisor.
    - Added pigpiod.conf for managing pigpiod service.
    - Introduced print.conf_ for managing print.py process with supervisor.
    - Added ui.conf for managing display.py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
    [display.py, generate_icons.py, mc.py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]
2026-03-27 Fix logging format in display.py and simplify UI command handling
    [LCD-cable-brackeer.FCStd]
2026-03-27 Add estimated total time calculation to PrintingScreen
